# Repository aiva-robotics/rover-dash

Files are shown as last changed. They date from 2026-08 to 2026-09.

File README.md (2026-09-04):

# RC Command Center

Skapa en modern, mobilanpassad webbapplikation för att fjärrstyra en radiostyrd bil med kamera. Designen ska kännas som en professionell kontrollstation för en robot eller FPV-fordon med mörkt tema, glasliknande paneler (glassmorphism), mjuka animationer och responsiv layout.

Layout:

- Överst visas en stor 16:9 livevideoström från Raspberry Pi-kameran med möjlighet till helskärm.

- Ovanpå videon ska en transparent Driving HUD visas med batterinivå, WiFi-signal, hastighet, styrvinkel, gaspådrag, inspelningsindikator och kompass (förberedd för framtida IMU).

- Under videon finns två virtuella joysticks:

  - Vänster joystick styr gas/broms.

  - Höger joystick styr vald RC-utgång på STM32-kortet.

  - Joysticks ska fungera med både touch och mus och automatiskt återgå till mitten när de släpps.

- Nederst finns fyra stora knappar:

  - Strålkastare

  - Tuta

  - Ta bild

  - Stor röd Nödstopp-knapp

Instrumentpanel:

Visa i realtid:

- Batterispänning

- WiFi-signal

- Anslutningsstatus

- Hastighet

- Temperatur (om tillgänglig)

- Ping till bilen

Kommunikation:

- Använd WebSocket.

- Skicka generiska STM32-kommandon kontinuerligt i JSON-format. Appen ansvarar
  för att mappa joystick/reglage till rätt RC-utgångar:

{

  "rc": [0, 0, 0, 0],

  "digital": 0,

  "buzzer": 0

}

- Ta emot status som JSON och uppdatera gränssnittet automatiskt.

Inställningar:

Skapa en inställningssida där användaren kan ändra:

- WebSocket-adress

- Videoadress

- Maxhastighet

- Joystickkänslighet

- Invertera styrning

- Invertera gas

Alla inställningar ska sparas i Local Storage.

Säkerhet:

Om anslutningen bryts ska:

- En stor röd varning visas.

- Alla reglage inaktiveras.

- Gränssnittet tydligt indikera att bilen gått till nödstopp.

Förbered gränssnittet för framtida funktioner:

- GPS-karta

- AI-objektdetektering

- Videoinspelning

- Flera kameror

- Batterihistorik

- Loggpanel

Bygg applikationen i React + TypeScript med en modulär komponentstruktur som är enkel att vidareutveckla.

This project was built with [Lovable](https://lovable.dev).

## Build with Lovable

Continue developing this project in the [Lovable editor](https://lovable.dev/projects/422cf66d-660f-4919-b7d5-5cbf4e8ac53d).

- **Ship faster**: describe what you want to build and Lovable handles the code.
- **Stay in sync**: every change made in Lovable is committed straight to this repository.
- **Full ownership**: this code is yours. Push to `main` on GitHub and your changes sync back into Lovable, ready for your next prompt.

## Development

Prefer working locally? You need Node.js and npm — [install with nvm](https://github.com/nvm-sh/nvm#installing-and-updating).

```sh
git clone <this-repository-url>
cd <repository-name>
npm i
npm run dev
```

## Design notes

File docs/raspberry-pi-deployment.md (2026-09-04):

# Raspberry Pi 3 deployment guide

Run the RC Control Station web app locally on a Raspberry Pi 3 so you can control the car from any device on the same network without relying on the cloud preview.

## What you need

- Raspberry Pi 3 (or newer) with Raspberry Pi OS Lite/Desktop
- SSH access to the Pi (`pi@raspberrypi.local` or its IP address)
- Either a faster dev machine to build the app before copying it, **or** patience to build it directly on the Pi

## How it works

The app is server-rendered, so the Pi runs a small Node server (built with the `node-server` target) behind nginx on port 80. The browser connects directly to the Raspberry Pi camera stream and the car WebSocket server.

You have two deployment options:

1. **Cross-build (recommended)** — Build on your dev machine and copy the server bundle to the Pi. Fast and gentle on the Pi.
2. **Native build** — Download the source to the Pi with `git` and build it there. Useful if you want to edit code directly on the Pi or do not have another computer.

If you already pushed the project to GitHub and want the Pi to fetch and build it automatically, see the **One-command clone + setup** shortcut in Option B.

---

## Option A: Cross-build (recommended)

### One-time Pi setup

SSH into the Pi and run:

```bash
sudo apt update
sudo apt install -y nginx nodejs
sudo systemctl enable nginx
```

### Deploy from your development machine

Set the target host (or edit `scripts/deploy-to-pi.sh`):

```bash
export PI_HOST=pi@raspberrypi.local
export PI_APP_DIR=/home/pi/rc-control-app
```

Use the Pi's IP address if `.local` does not resolve on your network.

Build and deploy:

```bash
NITRO_PRESET=node-server bun run build
bun run deploy:pi
```

This copies the `.output/` server bundle to the Pi, installs the `rc-control` systemd service and the nginx reverse proxy, and starts the app.

Open the app on any device on the same network:

```
http://raspberrypi.local
```

### Updating after code changes

Run the same two commands again:

```bash
NITRO_PRESET=node-server bun run build
bun run deploy:pi
```

---

## Option B: Build natively on the Raspberry Pi

> ⚠️ **Warning:** A Pi 3 only has 1 GB RAM. The Vite/TanStack build is heavy and can take 10–30 minutes, or longer if swap is too small. A Pi 4/5 with more RAM is much more comfortable. The scripts below configure extra swap to make the build possible.

### 1. Download the project from GitHub

SSH into the Pi and clone your repository. Replace the URL below with your own repo URL:

```bash
cd ~
git clone https://github.com/YOUR_USERNAME/YOUR_REPO_NAME.git rc-control-app
cd rc-control-app
```

#### Private repositories

If your GitHub repository is private, use **one** of these methods on the Pi:

**A. SSH key (recommended if you use the Pi often)**

1. Generate or copy an SSH key to the Pi:
   ```bash
   ssh-keygen -t ed25519 -C "pi@raspberrypi"
   cat ~/.ssh/id_ed25519.pub
   ```
2. Add the key in GitHub under **Settings → SSH and GPG keys → New SSH key**.
3. Clone with the SSH URL:
   ```bash
   git clone git@github.com:YOUR_USERNAME/YOUR_REPO_NAME.git rc-control-app
   ```

**B. Personal access token (good for one-command setup)**

1. Create a token in GitHub under **Settings → Developer settings → Personal access tokens → Tokens (classic)**. Give it at least the `repo` scope.
2. On the Pi, export the token and run the helper script:
   ```bash
   export REPO_URL=https://github.com/YOUR_USERNAME/YOUR_REPO_NAME.git
   export GITHUB_TOKEN=ghp_xxxxxxxxxxxxxxxxxxxx
   bash scripts/pi-clone-and-setup.sh
   ```
   The script uses the token only during clone/pull and does **not** save it in `.git/config`.

**C. Manual token clone**

```bash
cd ~
git clone https://ghp_xxxxxxxxxxxxxxxxxxxx@github.com/YOUR_USERNAME/YOUR_REPO_NAME.git rc-control-app
cd rc-control-app
# Remove the token from the stored origin URL so it is not saved on disk
git remote set-url origin https://github.com/YOUR_USERNAME/YOUR_REPO_NAME.git
```

> **Note:** The one-command `curl ... | bash` shortcut below only works for **public** repositories, because `raw.githubusercontent.com` cannot fetch files from a private repo without authentication.

To update the app later after pushing changes from another machine:

```bash
cd ~/rc-control-app
# For a public repo or an SSH-cloned private repo:
git pull
# For a private HTTPS repo with a token:
export GITHUB_TOKEN=ghp_xxxxxxxxxxxxxxxxxxxx
bash scripts/pi-clone-and-setup.sh
bash scripts/pi-build.sh
```

### One-command clone + setup shortcut (public repos only)

If your repo is public and you want the Pi to download, build, and serve the app in one go, SSH in and run:

```bash
export REPO_URL=https://github.com/YOUR_USERNAME/YOUR_REPO_NAME.git
curl -fsSL https://raw.githubusercontent.com/YOUR_USERNAME/YOUR_REPO_NAME/main/scripts/pi-clone-and-setup.sh | bash
```

Or, after cloning once, run the included script directly (this works with `GITHUB_TOKEN` for private repos too):

```bash
export REPO_URL=https://github.com/YOUR_USERNAME/YOUR_REPO_NAME.git
export GITHUB_TOKEN=ghp_xxxxxxxxxxxxxxxxxxxx   # only needed for private repos
bash scripts/pi-clone-and-setup.sh
```

This clones/updates the repo, installs dependencies, builds the app, configures nginx, and enables auto-start on boot.

### 2. Prepare the Pi

Run the setup script inside the project directory:

```bash
cd rc-control-app
bash scripts/pi-build-setup.sh
```

This installs Node.js, bun, nginx, git, and configures a 2 GB swap file.

### 3. Build the app on the Pi

Inside the project directory on the Pi:

```bash
bash scripts/pi-build.sh
```

The script limits Node's memory usage, installs optional dependencies (needed for Rolldown), and builds a self-hosted Node server bundle (`NITRO_PRESET=node-server` → `.output/server/index.mjs`).

When the build finishes it **deploys automatically**:

- installs the `rc-control` systemd service that runs `.output/server/index.mjs` on port 3000 (auto-start on boot)
- installs the nginx reverse proxy config on port 80 and reloads nginx
- starts the service and verifies it is running

Skip the deploy step with:

```bash
DEPLOY=false bash scripts/pi-build.sh
```

Deploy an existing build separately with:

```bash
bash scripts/pi-deploy-local.sh   # or: npm run pi:deploy
```

### 4. Managing the app

```bash
sudo systemctl status rc-control      # is it running?
sudo journalctl -u rc-control -f      # live logs
sudo systemctl restart rc-control     # restart after a rebuild
```

Run the server in the foreground (without systemd) with:

```bash
bash scripts/pi-serve.sh              # PORT=3000 by default
```

---

## No nginx?

The app also works without nginx — it just runs on port 3000 instead of 80:

```
http://raspberrypi.local:3000
```

---

## Troubleshooting

- **`Cannot find module '.../lightningcss.linux-arm64-gnu.node'`**: Tailwind v4 compiles CSS with lightningcss, whose native binary is also an *optional* dependency. `pi-build.sh` now installs `lightningcss-linux-arm64-gnu` automatically; if it still fails, run a clean install as shown below.
- **`Cannot find module './rolldown-binding.linux-arm64-gnu.node'`**: The build tool (Vite 8 / Rolldown) needs a native binary that is installed as an *optional* dependency. Do a clean install with optional deps enabled:
  ```bash
  cd ~/rc-control-app
  rm -rf node_modules package-lock.json
  npm install --include=optional
  bash scripts/pi-build.sh
  ```
  Make sure you are **not** setting `npm_config_optional=false` and that you run the 64-bit Raspberry Pi OS — check with `uname -m` (must print `aarch64`). On a 32-bit OS (`armv7l`) there is no prebuilt binary; either reflash with the 64-bit image or use the cross-build workflow (Option A).
- **`build output not found at dist/client`**: older builds targeted Cloudflare and produced no static site. Pull the latest code and rebuild — `pi-build.sh` now sets `NITRO_PRESET=node-server` and produces `.output/server/index.mjs`.
- **Cannot reach the page**: make sure the Pi firewall allows port 80/3000 and the device is on the same network. Check `sudo systemctl status rc-control`.
- **Page loads but car does not connect**: the browser must be able to reach the WebSocket address configured in Settings. The Pi only serves the web files; it does not proxy the car connection by default.
- **Build fails with OOM / JavaScript heap out of memory**: The Pi 3 needs more swap. Run `scripts/pi-build-setup.sh` again to ensure the 2 GB swap file is active, or increase it further with `sudo dphys-swapfile swapoff && sudo nano /etc/dphys-swapfile`.
- **Build takes forever**: This is expected on a Pi 3. Use the cross-build workflow (Option A) for faster iteration.

## Raspberry Pi-kamera (MJPEG-stream)

Appen visar video via en MJPEG-ström. På Pi:n körs en liten Python-server
(`deployment/pi-camera-server.py`) som använder `picamera2` och levererar
strömmen direkt i ett format webbläsaren förstår.

### Installation

```bash
cd ~/rc-control        # projektmappen på Pi:n
bash scripts/pi-camera-setup.sh
```

Skriptet installerar `python3-picamera2`, lägger till användaren i gruppen
`video`, installerar systemd-tjänsten `pi-camera.service` och startar den.

### Adresser

| Endpoint | Beskrivning |
| --- | --- |
| `http://<pi-ip>:8080/stream` | MJPEG-ström |
| `http://<pi-ip>:8080/snapshot` | Enstaka JPEG-bild |
| `http://<pi-ip>:8080/health` | JSON-status |
| `http://<pi-ip>/camera/stream` | Samma ström via nginx (rekommenderas) |

Sätt **Videoadress** i appens inställningar — det finns två snabbknappar
("Pi-kamera (via nginx)" och "Pi-kamera (port 8080)").

Kör `sudo bash scripts/pi-deploy-local.sh` igen efter uppdateringen så att
nginx får `/camera/`-proxyn.

### Konfiguration

Du kan vända bilden på två ställen:

1. **I appen (rekommenderat)** — gå till **Inställningar** och slå på
   "Vänd bild horisontellt" / "Vänd bild vertikalt". Detta görs med CSS-transform
   i webbläsaren och kostar ingen prestanda.
2. **I kameran (hårdvarunivå)** — sätt `CAM_HFLIP=1` eller `CAM_VFLIP=1` i
   tjänsten. Detta använder libcamera `Transform` och har i princip noll
   prestandapåverkan.

Redigera miljövariablerna i tjänsten:

```bash
sudo systemctl edit --full pi-camera
```

| Variabel | Default | Beskrivning |
| --- | --- | --- |
| `CAM_WIDTH` / `CAM_HEIGHT` | 640 / 480 | Upplösning (Pi 3: håll dig ≤ 1280x720) |
| `CAM_FPS` | 20 | Bildrutor per sekund |
| `CAM_QUALITY` | 75 | JPEG-kvalitet (lägre = mindre bandbredd) |
| `CAM_HFLIP` / `CAM_VFLIP` | 0 | Spegla bilden i kameran (upp och ner / spegelvänd) |

Starta om efter ändring: `sudo systemctl restart pi-camera`

### Felsökning

```bash
sudo systemctl status pi-camera
journalctl -u pi-camera -f
libcamera-hello --list-cameras     # hittas kameran?
curl -I http://localhost:8080/snapshot
```

- **Ingen kamera hittas:** kontrollera flatkabeln (blå sida mot Ethernet-porten)
  och att `camera_auto_detect=1` finns i `/boot/firmware/config.txt` (Bookworm).
- **"Device or resource busy":** något annat använder kameran — stoppa
  `libcamera-vid`/`motion` eller kör `sudo systemctl restart pi-camera`.
- **Hackig bild på Pi 3:** sänk `CAM_FPS` till 15 och `CAM_QUALITY` till 60.

---

## Styrserver: WebSocket till STM32 UART (rc-car-server)

Pi:n tar emot WebSocket-kommandon från appen och skickar dem vidare till
STM32-kortet över `/dev/serial0`. STM32-kortet hanterar RC-utgångar,
digitala utgångar, buzzer, status och OLED.

### Koppling

| Signal | Raspberry Pi 3 | STM32 |
| --- | --- | --- |
| UART TX | GPIO14 / pin 8 | STM32 UART RX |
| UART RX | GPIO15 / pin 10 | STM32 UART TX |
| GND | pin 6 / 9 / 14 / 20 / 25 / 30 / 34 / 39 | GND |
| Power-off ready | GPIO26 / pin 37 | RPI_POWER_OFF_OK |

RC-servon och digitala utgångar kopplas till STM32-kortets utgångar, inte
direkt till Raspberry Pi GPIO.

### Installation

```bash
bash scripts/pi-car-server-setup.sh
```

Skriptet installerar Python/WebSocket/serial-beroenden och tjänsten
`rc-car-server` (startar automatiskt vid boot, port 81).

Sätt **WebSocket-adress** i inställningarna till `ws://<pi-ip>:81` (eller tryck
på snabbknappen "Pi WebSocket (samma värd)").

### Beteende

- Tar emot generiska STM32-kommandon:
  `{"rc": [0, 0, 0, 0], "digital": 0, "buzzer": 0}`.
- Mappning av joystick, servo, motor, lampor och buzzer görs i webbappen.
- Svarar `{"pong": ...}` på ping så appen kan mäta latens.
- Skickar telemetri 5 ggr/s (hastighet, CPU-temp, WiFi-RSSI, status).
- **Watchdog:** inga kommandon på 0,5 s → generiska RC-kommandon till neutral.
- **En förare i taget** — en ny klient tar över och den gamla får ett tydligt
  felmeddelande i appen.
- STM32-bron armeras med 2 s neutrala kommandon vid start.

Justera UART-port, heartbeat, auth-token och timeouts med
`sudo systemctl edit --full rc-car-server`.

### Felsökning

```bash
sudo systemctl status rc-car-server
journalctl -u rc-car-server -f
```

---

## Statusskärm

Statusskärmen (IP-adress m.m.) hanteras numera av STM32-kortet på Raspberry
Pi-hatten, inte av någon tjänst på Pi:n.

---

## Uppdatera allt med ett kommando

```bash
bash scripts/pi-deploy-all.sh
```

Skriptet:

1. hämtar senaste koden från GitHub (`GITHUB_TOKEN=xxx` för privata repon),
2. bygger webbappen,
3. installerar/uppdaterar alla systemd-tjänster (webb, kamera, styrserver),
4. aktiverar dem så de startar vid boot och skriver ut en hälsokontroll.

Användbara flaggor: `SKIP_BUILD=1`, `WITH_CAMERA=0`,
`WITH_CAR_SERVER=0`, `BRANCH=main`.

## Åtkomsttoken (autentisering)

Utan token kan vem som helst på nätverket styra bilen. Sätt en delad hemlighet:

```bash
sudo systemctl edit --full rc-car-server   # ändra Environment=RC_TOKEN=minhemlighet
sudo systemctl restart rc-car-server
```

Ange samma värde i appen under **Inställningar → Åtkomsttoken**. Appen lägger på
det som `?token=...` på WebSocket-adressen; fel token ger felmeddelandet
"Fel åtkomsttoken" i gränssnittet.

## Tillbehör och säkerhet (uppdaterat)

Nya miljövariabler för `rc-car-server.service`:

| Variabel | Standard | Beskrivning |
| --- | --- | --- |
| `RC_SNAPSHOT_URL` | `http://127.0.0.1:8080/snapshot` | Källa för "Ta bild" |
| `RC_PHOTO_DIR` | `/var/lib/rc-car/photos` | Där bilder sparas |

Åtkomsttoken skickas numera i WebSocket-handskakningen (`Sec-WebSocket-Protocol`)
istället för i URL:en, så den hamnar inte i nginx- eller proxyloggar. Servern
accepterar fortfarande `?token=` från äldre klienter men loggar en varning.

Appen upptäcker även "halvöppna" anslutningar: om bilen slutar svara på ping
inom 3,5 sekunder kopplas socketen ner, varningen visas och reglagen låses.

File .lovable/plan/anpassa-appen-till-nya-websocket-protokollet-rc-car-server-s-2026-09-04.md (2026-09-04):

# Anpassa appen till nya WebSocket-protokollet (rc-car-server.service)

Servern (STM32-bryggan) accepterar inte längre `{throttle, steering}`. Den förväntar sig
`{"rc": [c1, c2, c3, c4], "digital": 0..15, "buzzer": 0..65535}` med värden -1000..1000,
plus `{"estop": bool}` och `{"action": ...}`. Appen skickar fortfarande det gamla formatet,
så styrningen når aldrig hårdvaran.

## Vad som ändras

1. **Kommandoformat**
   - Skala appens -100..100 till -1000..1000.
   - Kanal 1 (index 0) = styrning, kanal 3 (index 2) = gas. Kanal 2 och 4 skickas som 0.
   - `estop` skickas som idag i samma paket.
   - Kommandot skickas fortfarande med 20 Hz (serverns watchdog kräver det).

2. **Tillbehör mot rätt fält**
   - Ljus: digital utgång bit 0 (`digital: 1`), skickas som del av det löpande kommandot
     så att STM32:ans failsafe inte släcker det.
   - Tuta: `buzzer` sätts till 2000 Hz medan knappen hålls/aktiveras, annars 0.
   - `sendAction("headlights"/"horn")` tas bort — servern känner inte igen dem.

3. **Telemetri och status**
   - Ljusstatus läses från serverns eko (`stm32.digitalMask`) istället för `status.headlights`.
   - `failsafe` från STM32 visas som varningsläge i gränssnittet (finns redan i typen).
   - Batteri kommer nu från INA226 (`battery` i volt) — befintlig visning fungerar,
     men procentskalan justeras inte i denna ändring.

4. **Typer**
   - `DriveCommand` utökas med `digital` och `buzzer` (valfria) i `src/lib/car-protocol.ts`.
   - `CarStatus` får `stm32?`-fältet typat så att digitalMask/failsafe kan läsas säkert.

## Berörda filer

- `src/lib/car-protocol.ts` – typer + skalningshjälpare (`toRcValue`).
- `src/hooks/useCarSocket.ts` – bygger `{rc, digital, buzzer, estop}`-paketet i sändloopen.
- `src/routes/index.tsx` – ljus/tuta styr nu kommandots `digital`/`buzzer`; läser ljusstatus
  från `stm32.digitalMask`.
- `src/components/car/ControlButtons.tsx` – oförändrat API, endast anropen kopplas om.

Inga ändringar i serverkoden eller deployment-skripten behövs.

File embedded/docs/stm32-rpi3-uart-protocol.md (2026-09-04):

# Rover Dash STM32 to Raspberry Pi 3 UART Protocol

This document describes the UART protocol used between the Rover Dash STM32 controller and a Raspberry Pi 3. It is intended as an architectural reference for reimplementing the Raspberry Pi side in another language, runtime, or application.

## Purpose

The Raspberry Pi is the high-level controller. The STM32 is the real-time I/O controller.

The Raspberry Pi sends control commands to the STM32 for:

- 4 generic RC PWM outputs
- 4 digital outputs
- Buzzer frequency
- Optional OLED framebuffer content

The STM32 sends status and telemetry back to the Raspberry Pi containing:

- Command echo
- Failsafe state
- Raspberry Pi power-management state
- ADC values
- NTC raw value
- TMP75 temperature
- Speed sensor value
- INA226 voltage and current

The STM32 can also send a shutdown request to the Raspberry Pi.

## Physical Link

```text
UART:        115200 baud
Data bits:   8
Parity:      none
Stop bits:   1
Flow control: none
Framing:     COBS + 0x00 delimiter
```

Each UART frame is COBS encoded and terminated with byte `0x00`.

## Packet Format Before COBS

Before COBS encoding, every packet has this format:

```text
byte 0:       message type
byte 1:       payload length
bytes 2..N:   payload
last 2 bytes: CRC16-CCITT, little-endian
```

The CRC is calculated over:

```text
message type + payload length + payload
```

CRC settings:

```text
CRC16-CCITT
Polynomial: 0x1021
Initial value: 0xFFFF
Output byte order: little-endian
```

## Message Types

```text
0x01 CONTROL       Raspberry Pi -> STM32
0x02 RPI_SHUTDOWN  STM32 -> Raspberry Pi
0x03 DISPLAY_DATA  Raspberry Pi -> STM32
0x04 DISPLAY_UPDATE Raspberry Pi -> STM32
0x05 RPI_INFO      Raspberry Pi -> STM32
0x80 STATUS        STM32 -> Raspberry Pi
0x81 DIAGNOSTICS   Reserved/optional
```

## CONTROL Packet

Direction:

```text
Raspberry Pi -> STM32
```

Message type:

```text
0x01
```

Payload length:

```text
11 bytes
```

Payload layout:

```text
0-1:  RC Output 0, int16 little-endian, range -1000..1000, maps to PA11
2-3:  RC Output 1, int16 little-endian, range -1000..1000, maps to PA10
4-5:  RC Output 2, int16 little-endian, range -1000..1000, maps to PA9
6-7:  RC Output 3, int16 little-endian, range -1000..1000, maps to PA8
8:    digital output bitmask, uint8
9-10: buzzer frequency Hz, uint16 little-endian
```

Digital output bitmask:

```text
bit 0: Digital Output 0, PA6
bit 1: Digital Output 1, PA7
bit 2: Digital Output 2, PB0
bit 3: Digital Output 3, PB1
```

Buzzer behavior:

```text
0 Hz:  buzzer off
>0 Hz: buzzer on at requested frequency
```

RC output scaling on STM32:

```text
-1000 -> 1000 us pulse
0     -> 1500 us pulse
+1000 -> 2000 us pulse
```

The Raspberry Pi should send `CONTROL` periodically while active. A good default rate is `20 Hz`. The STM32 output failsafe timeout is currently `1000 ms`; if no valid `CONTROL` packet is received within that time, RC outputs return to neutral, digital outputs turn off, and the buzzer turns off.

## RPI_SHUTDOWN Packet

Direction:

```text
STM32 -> Raspberry Pi
```

Message type:

```text
0x02
```

Payload length:

```text
0 bytes
```

Meaning:

The STM32 requests that the Raspberry Pi shut down cleanly.

The Raspberry Pi should respond by starting its OS shutdown sequence. Before final poweroff, the Raspberry Pi should assert its shutdown-ready signal connected to:

```text
STM32 input:       RPI_POWER_OFF_OK
Raspberry Pi GPIO: GPIO26
```

The STM32 then disables `REG_5V_EN` and removes Raspberry Pi power.

## OLED Ownership And Framebuffer Display

The STM32 owns the physical OLED display at all times. The Raspberry Pi must not access the OLED I2C bus directly. If the Raspberry Pi wants to draw on the OLED, it sends a complete 128x32 monochrome framebuffer over UART and the STM32 decides whether to show it.

The STM32 keeps two independent 512-byte framebuffers:

```text
local_framebuffer: STM32-generated status and warning display
rpi_framebuffer:   latest complete framebuffer received from Raspberry Pi
```

The OLED framebuffer is arranged as 4 pages of 128 bytes. Each byte represents one vertical column of 8 pixels, matching the SSD1306 page format.

At startup the active display source is always STM32/local. This lets the STM32 show local startup and power-management messages before the Raspberry Pi has booted.

Typical local STM32 messages include:

```text
ROVERCORE
STARTING...

RASPBERRY PI
BOOTING...

RASPBERRY PI
CONNECTED

RASPBERRY PI
SHUTDOWN

RASPBERRY PI
POWER OFF

POWER FAULT
PI DISABLED
```

### DISPLAY_DATA Packet

Direction:

```text
Raspberry Pi -> STM32
```

Message type:

```text
0x03
```

Payload layout:

```text
byte 0:     chunk number, 0..8
bytes 1..N: framebuffer data bytes
```

Chunk sizes:

```text
chunks 0..7: payload length 64 bytes, containing 63 framebuffer bytes
chunk 8:     payload length 9 bytes, containing 8 framebuffer bytes
```

For compatibility, the STM32 also accepts chunk `8` with payload length `64` and ignores padding beyond the final 8 framebuffer bytes.

The framebuffer byte offset for each chunk is:

```text
offset = chunk_number * 63
```

Receiving `DISPLAY_DATA` does not immediately change what is shown on the OLED. The STM32 only stores the data in `rpi_framebuffer`.

### DISPLAY_UPDATE Packet

Direction:

```text
Raspberry Pi -> STM32
```

Message type:

```text
0x04
```

Payload length:

```text
0 bytes
```

When `DISPLAY_UPDATE` is received, the STM32 shows `rpi_framebuffer` only if all 9 chunks have been received. Incomplete framebuffer transfers are ignored and the currently displayed source remains unchanged.

The Raspberry Pi does not need to retransmit the framebuffer after a temporary STM32 local display override. The STM32 keeps the latest valid Raspberry Pi framebuffer stored separately.

The Raspberry Pi should keep the periodic `CONTROL` stream running while sending display chunks. Display packets count as Raspberry Pi communication, but they do not refresh the output-control failsafe timer.

At `115200 baud`, one full-size encoded display chunk takes roughly `6 ms` on the UART line. The STM32 UART receive path is sized to accept a complete 9-chunk display burst, but the Raspberry Pi should still serialize writes in order and avoid overlapping writes from multiple async producers.

## RPI_INFO Packet

Direction:

```text
Raspberry Pi -> STM32
```

Message type:

```text
0x05
```

Payload length:

```text
1..15 bytes
```

Payload layout:

```text
0..N: Raspberry Pi IPv4 address as ASCII text, without NUL terminator
```

Example payload:

```text
31 39 32 2E 31 36 38 2E 31 2E 34 32
```

This represents:

```text
192.168.1.42
```

The Raspberry Pi should send this packet after opening the UART and whenever the active IP address changes. The STM32 stores the address and displays it on the connected Raspberry Pi status screen.

## STATUS Packet

Direction:

```text
STM32 -> Raspberry Pi
```

Message type:

```text
0x80
```

Payload length:

```text
56 bytes
```

Payload layout:

```text
0-3:   uptime_ms, uint32 little-endian

4-5:   RC Output 0 echo, int16 little-endian
6-7:   RC Output 1 echo, int16 little-endian
8-9:   RC Output 2 echo, int16 little-endian
10-11: RC Output 3 echo, int16 little-endian

12:    digital_output_mask, uint8
13:    failsafe_active, uint8 boolean
14-15: buzzer_frequency_hz, uint16 little-endian

16-19: uart_rx_frames, uint32 little-endian
20-23: uart_crc_errors, uint32 little-endian
24-27: failsafe_count, uint32 little-endian

28-29: rpi_connected, uint16 boolean little-endian
30:    rpi_power_enabled, uint8 boolean
31:    rpi_poweroff_ok, uint8 boolean
32:    rpi_shutdown_requested, uint8 boolean
33:    rpi_status, uint8

34-35: ADC PA0 raw, uint16 little-endian
36-37: ADC PA1 raw, uint16 little-endian
38-39: ADC PA2 raw, uint16 little-endian
40-41: ADC PA3 raw, uint16 little-endian

42-43: NTC PA4 raw, uint16 little-endian

44-45: TMP75 temperature, int16 little-endian, centi-Celsius
46:    TMP75 valid flag, uint8 boolean

47-50: speed_hz_x100, uint32 little-endian

51-52: INA226 bus voltage, uint16 little-endian, millivolts
53-54: INA226 current, int16 little-endian, milliamps
55:    INA226 valid flag, uint8 boolean
```

Display conversions:

```text
uptime_s = uptime_ms / 1000
tmp75_c = tmp75_centi_c / 100
speed_hz = speed_hz_x100 / 100
ina226_voltage_v = ina226_bus_voltage_mv / 1000
ina226_current_a = ina226_current_ma / 1000
```

`rpi_status` values:

```text
0: Boot delay
1: Waiting for ready
2: Running
3: Shutdown requested
4: Powered off
5: Forced off
```

## Startup And Power Behavior

On STM32 startup:

1. `REG_5V_EN` is held low.
2. STM32 waits approximately `100 ms`.
3. STM32 enables `REG_5V_EN`.
4. STM32 enters forced failsafe while waiting for the Raspberry Pi.
5. When the Raspberry Pi starts sending valid `CONTROL` packets, STM32 marks `rpi_connected` true.
6. Forced failsafe is released.

While in failsafe:

```text
RC outputs     -> neutral
digital outputs -> off
buzzer         -> off
```

## Shutdown Behavior

If the user presses the power button on STM32:

1. STM32 enters failsafe.
2. STM32 sends an `RPI_SHUTDOWN` packet.
3. STM32 repeats the shutdown packet until `RPI_POWER_OFF_OK` is detected.
4. Raspberry Pi should assert GPIO26 when it is safe to remove power.
5. STM32 disables `REG_5V_EN`.

If the user holds the power button for a long press, currently around `3000 ms`, the STM32 forces Raspberry Pi power off by disabling `REG_5V_EN`.

## Raspberry Pi Implementation Requirements

A Raspberry Pi implementation should:

1. Open UART at `115200 8N1`.
2. Read bytes continuously.
3. Split frames on `0x00`.
4. Ignore empty frames.
5. COBS-decode each frame.
6. Validate packet length.
7. Validate CRC.
8. Dispatch by message type.
9. Send `CONTROL` packets periodically while running.
10. Listen for `RPI_SHUTDOWN`.
11. On shutdown request, safely stop application logic and initiate OS shutdown.
12. Assert GPIO26 / `RPI_POWER_OFF_OK` before final poweroff if hardware and software allow it.

The Pi should treat invalid CRC, invalid COBS, or wrong payload length as protocol errors and ignore that frame.

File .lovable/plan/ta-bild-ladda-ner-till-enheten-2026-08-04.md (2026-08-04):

# Ta bild – ladda ner till enheten

Fotoknappen finns redan men sparar bilden på bilens SD-kort. Nu ska ett tryck även ge dig bilden direkt i telefonen/datorn.

## Så fungerar det

- Tryck på **Bild** (samma knapp som idag, även i helskärm) → aktuell bildruta från videoströmmen fångas och laddas ner som JPEG.
- Filnamn: `rc-bild-ÅÅÅÅMMDD-HHMMSS.jpg`.
- Kort visuell bekräftelse: en snabb "blixt" över videon plus en rad i loggen ("Bild sparad: …").
- Bilden speglas/vänds precis som videon visas, så nedladdningen matchar det du ser.
- Fungerar även i demoläge? Nej – utan videoström visas ett tydligt meddelande "Ingen videoström att fånga".
- Bilden sparas fortfarande på bilen som tidigare (oförändrat beteende).

## Teknisk lösning

**`src/components/car/VideoFeed.tsx`**
- Exponera en `captureFrame()`-funktion via `useImperativeHandle` (forwardRef) som ritar `imgRef.current` till en offscreen `<canvas>` i naturlig upplösning, applicerar `videoFlipH`/`videoFlipV` som canvas-transform, och returnerar en `Blob` via `canvas.toBlob(..., "image/jpeg", 0.92)`.
- Sätt `crossOrigin="anonymous"` på `<img>` så att canvasen inte blir "tainted" när kameraservern ligger på en annan port/origin (den skickar redan `Access-Control-Allow-Origin: *`).
- Fallback när canvas ändå är tainted eller bilden inte laddat: hämta `/<samma bas>/snapshot` med `fetch` och använd den blobben.
- Lägg till en kort blixt-overlay (150 ms, CSS-opacity) vid lyckad fångst.

**`src/routes/index.tsx`**
- Ny `videoRef` till `VideoFeed`.
- `onPhoto` blir en `handlePhoto()`-callback: skickar `sendAction("photo")` som idag, anropar `videoRef.current?.captureFrame()`, skapar en objekt-URL och triggar nedladdning via ett temporärt `<a download>`-element (URL:en revokeas direkt efter).
- Fel loggas som `log("error", …)` i den befintliga loggpanelen.

Inga ändringar behövs på Raspberry Pi-sidan.

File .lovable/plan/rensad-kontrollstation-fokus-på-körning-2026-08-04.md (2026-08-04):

# Rensad kontrollstation — fokus på körning

Idag visas allt samtidigt på startsidan: video + HUD, förarpanel, telemetri (6 rutor), joysticks, knappar, anslutningshälsa (12 mätvärden), framtidspaneler och logg. Det blir en lång, rörig sida där det viktiga (video, styrning, nödstopp) drunknar.

## Nytt upplägg

**Alltid synligt (ovanför "vecket"):**
- Videoströmmen med HUD (batteri, wifi, hastighet, gas/ratt, läge)
- Joysticks
- Kontrollknappar (ljus, tuta, foto, nödstopp)
- En smal statusrad högst upp: AIVA Robotics-logga till vänster, anslutningsprick + ping + batteri + "Du styr"/"Annan styr" i komprimerad form till höger

**Dolt bakom en "Detaljer"-panel (utfällbar längst ner, stängd som standard):**
- Full telemetri (spänning, dBm, temperatur, hastighet, ping)
- Anslutningshälsa (jitter, min/medel/max, paketförlust, försök, meddelanden)
- Förarpanel med sessions-ID och övertagningshistorik
- Logg

**Fortsatt påträngande när det behövs:**
- Nödstopp och anslutningsbortfall visas som idag med tydligt överlägg — ingenting av säkerhetsvärde göms.
- Om anslutningen tappas eller pingen blir dålig lyfts ett kort felmeddelande upp i statusraden även om detaljpanelen är stängd.

## Teknisk avgränsning

- Endast presentation ändras. `useCarSocket`, protokoll, inställningar och serverkod rörs inte.
- Ny komponent `src/components/car/StatusBar.tsx` (kompakt topprad) som innehåller AIVA Robotics-loggan.
- Loggan renderas som text/SVG ("AIVA Robotics") i subtil stil — ingen bildresurs krävs, men om användaren har en logotypfil kan den ersätta texten senare.
- Ny komponent `src/components/car/DetailsDrawer.tsx` som samlar befintliga `TelemetryPanel`, `ConnectionHealthPanel`, `DriverPanel` och `LogPanel` i en shadcn `Accordion`/`Collapsible`, öppet läge sparas i localStorage via befintlig settings-hook-stil (eller lokal state om vi vill hålla settings orörd).
- `FuturePanels` (GPS/AI-platshållare) tas bort helt från sidan och komponentfilen raderas.
- `src/routes/index.tsx` byggs om till: header/statusrad → video+HUD → joysticks → knappar → detaljlåda.
- Befintliga paneler behålls oförändrade internt, bara flyttade.

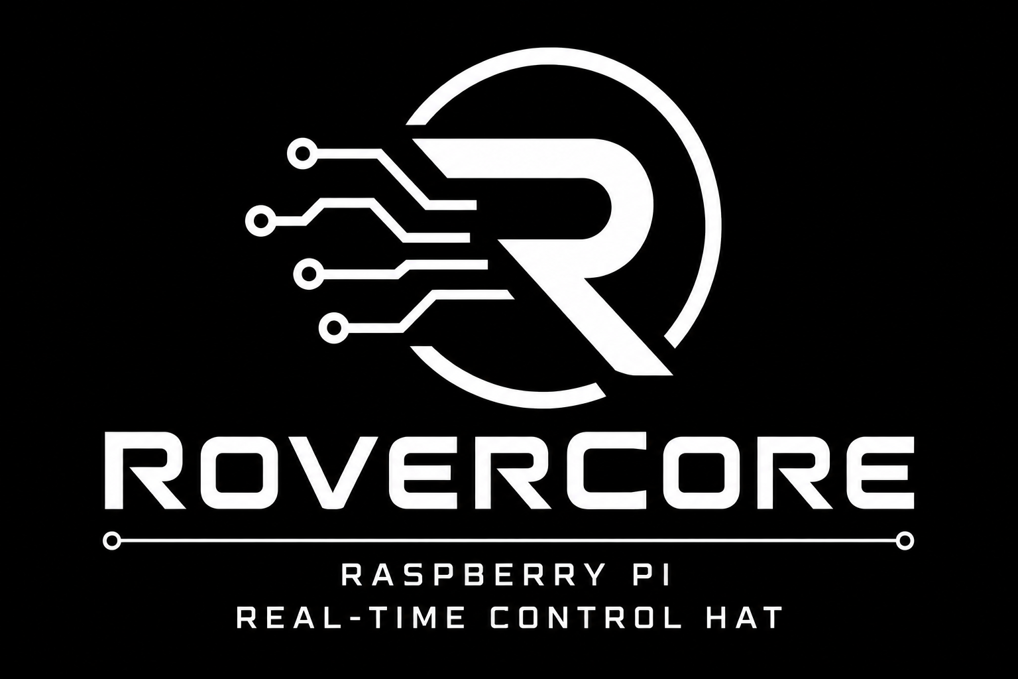
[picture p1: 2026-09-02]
rovercore.png

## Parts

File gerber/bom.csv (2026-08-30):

RefDes | Value | Name | Part | Pattern
C1 | 1uF | CAP_0805 | Part 1 | CAP_0603_N
C2 | 1uF | CAP_0805 | Part 1 | CAP_0603_N
C3 | 100nF | CAP_0805 | Part 1 | CAP_0603_N
C4 | 100nF | CAP_0805 | Part 1 | CAP_0603_N
C5 | 100nF | CAP_0805 | Part 1 | CAP_0603_N
C6 | 100nF | CAP_0805 | Part 1 | CAP_0603_N
C7 | 100nF | CAP_0805 | Part 1 | CAP_0603_N
C8 | 100nF | CAP_0805 | Part 1 | CAP_0603_N
C9 | 100nF | CAP_0805 | Part 1 | CAP_0603_N
C10 | 100nF | CAP_0805 | Part 1 | CAP_0603_N
C11 | 100nF | CAP_0805 | Part 1 | CAP_0603_N
C12 | 1uF | CAP_0805 | Part 1 | CAP_0603_N
C13 | 100nF | CAP_0805 | Part 1 | CAP_0603_N
C15 | 100nF | CAP_0805 | Part 1 | CAP_0603_N
D6 |  | LED_0805(2012 Metric)_N_Blue | Part 1 | LED_0805(2012 Metric)_N_Blue
J1 |  | RaspberryPi IO | Part 1 | HDR-2x20
JP1 |  | IDC_2pins | Part 1 | IDC_1x2
JP6 |  | IDC_2pins | Part 1 | IDC_1x2
JP7 |  | IDC_4pins | Part 1 | HDR-2x2
JP8 |  | IDC_4pins | Part 1 | IDC_1x4
JP15 |  | IDC_3pins | Part 1 | IDC_1x3
JP16 |  | IDC_2pins | Part 1 | IDC_1x2
L1 |  | IND_FERRITE_BEAD | Part 1 | RES_0603_N
LS1 |  | BUZZER | Part 1 | Buzzer
MD1 |  | S13V30F5 | Part 1 | D:\OneDrive\Documents\DipTrace\My Libraries
Q2 |  | AO3400A | Part 1 | SOT23-3P95_280X125L45X40N_AD1
Q3 |  | AO3400A | Part 1 | SOT23-3P95_280X125L45X40N_AD1
Q4 |  | AO3400A | Part 1 | SOT23-3P95_280X125L45X40N_AD1
Q5 |  | AO3400A | Part 1 | SOT23-3P95_280X125L45X40N_AD1
R1 | 220 | RES_0805 | Part 1 | RES_0603_N
R2 | 220 | RES_0805 | Part 1 | RES_0603_N
R3 | 4k7 | RES_0805 | Part 1 | RES_0603_N
R4 | 4k7 | RES_0805 | Part 1 | RES_0603_N
R5 |  | RES_0805 | Part 1 | RES_0603_N
R6 | 220 | RES_0805 | Part 1 | RES_0603_N
R7 | 220 | RES_0805 | Part 1 | RES_0603_N
R8 | 100k | RES_0805 | Part 1 | RES_0603_N
R9 | 100k | RES_0805 | Part 1 | RES_0603_N
R10 | 100k | RES_0805 | Part 1 | RES_0603_N
R11 | 10k | RES_0805 | Part 1 | RES_0603_N
R12 | 100k | RES_0805 | Part 1 | RES_0603_N
R13 | 100 | RES_0805 | Part 1 | RES_0603_N
R14 | 100 | RES_0805 | Part 1 | RES_0603_N
R15 | 100 | RES_0805 | Part 1 | RES_0603_N
R16 | 100 | RES_0805 | Part 1 | RES_0603_N
R17 | 100 | RES_0805 | Part 1 | RES_0603_N
R19 | 12k | RES_0805 | Part 1 | RES_0603_N
R20 | 20k | RES_0805 | Part 1 | RES_0603_N
R21 | 1k | RES_0805 | Part 1 | RES_0603_N
R22 | 12k | RES_0805 | Part 1 | RES_0603_N
R23 | 20k | RES_0805 | Part 1 | RES_0603_N
R24 | 1k | RES_0805 | Part 1 | RES_0603_N
R25 | 12k | RES_0805 | Part 1 | RES_0603_N
R26 | 20k | RES_0805 | Part 1 | RES_0603_N
R27 | 1k | RES_0805 | Part 1 | RES_0603_N
R28 | 12k | RES_0805 | Part 1 | RES_0603_N
R29 | 20k | RES_0805 | Part 1 | RES_0603_N
R30 | 1k | RES_0805 | Part 1 | RES_0603_N
R31 | 1k | RES_0805 | Part 1 | RES_0603_N
R32 | 10k | RES_0805 | Part 1 | RES_0603_N
R33 | 10k | RES_0805 | Part 1 | RES_0603_N
R34 | 1k | RES_0805 | Part 1 | RES_0603_N
R35 | 10k | RES_0805 | Part 1 | RES_0603_N
R36 | 10k | RES_0805 | Part 1 | RES_0603_N
R37 | 1k | RES_0805 | Part 1 | RES_0603_N
S1 |  | Switch_4x3mm_SMD | Part 1 | Switch_4x3mm_SMD
U1 |  | STM32G4A1CET | Part 1 | QFP48P50_900X900X120L50X22N
U2 |  | TagConnect | Part 1 | TagConnector
U3 |  | TPS7A24 | Part 1 | SOT23-5P95_280X145L45X40
U4 |  | TMP1075 | Part 1 | SOIC8P127_493X599X173L64X41L_AD4
U5 |  | IDC_2.54mm_3x4_straight | Part 1 | 2.54mm 3x4 straight
U6 |  | IDC_2.54mm_3x4_straight | Part 1 | 2.54mm 3x4 straight
U7 |  | IDC_2.54mm_3x4_straight | Part 1 | 2.54mm 3x4 straight
 |  | NTC
 |  | IN226
 |  | HALL Sensor DRV5033

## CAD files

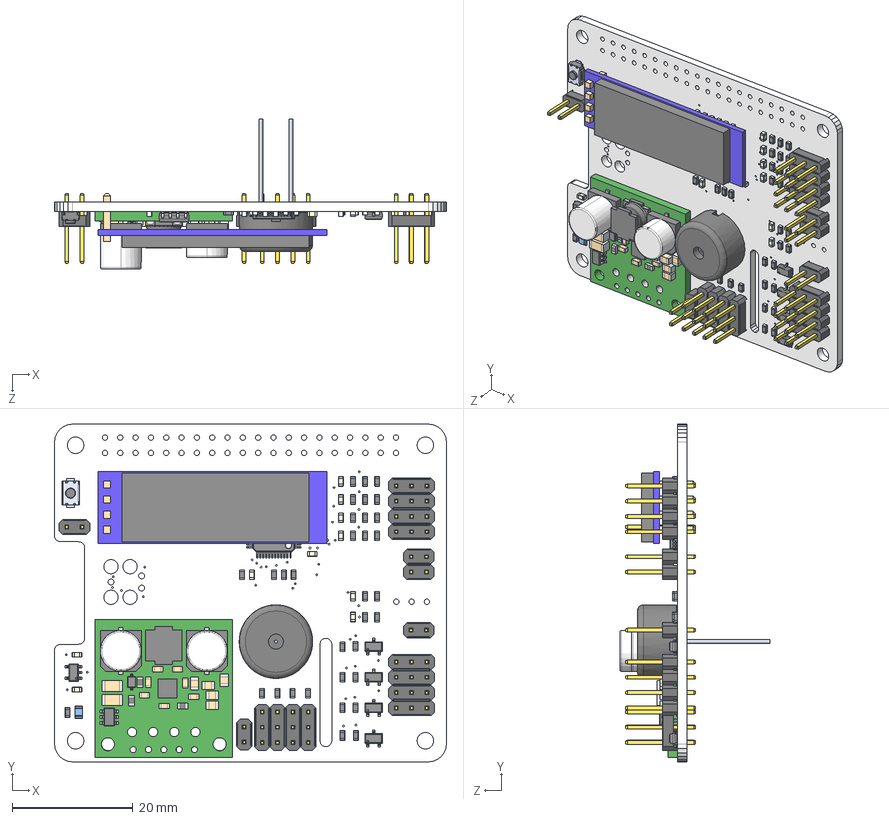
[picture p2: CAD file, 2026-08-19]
3d/mainboard.step
65.0 x 56.0 x 24.9 mm
Board_mainboard
CAP_0805 x 14
led_0805(2012_metric)_blue
PLD-2 x 3
PLD-4
UGV_OLED_Display_32x128
IND_FERRITE_BEAD x 37
PS1240P02BT
5v-step-up-step-down-voltage-regulator-s13v30f5
AO3400A x 4
TS-1088-AR02016--3DModel-STEP-269445
STM32G4A1KE
TPS7A24
TMP1075
PLT-12 x 3

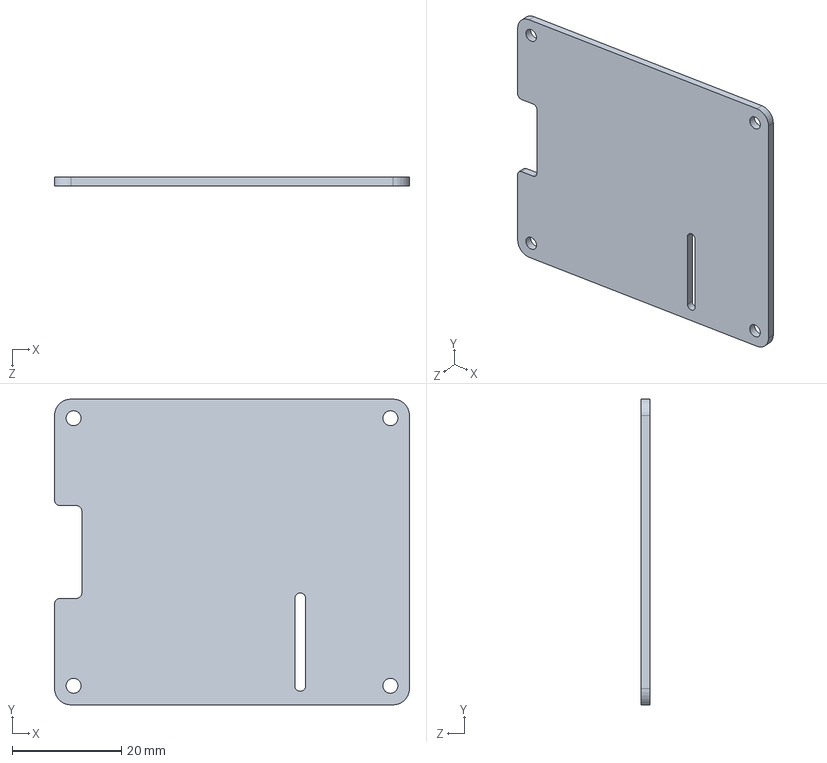
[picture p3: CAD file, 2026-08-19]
3d/raspberry_pi_hat.SLDPRT
65.0 x 56.0 x 1.60 mm

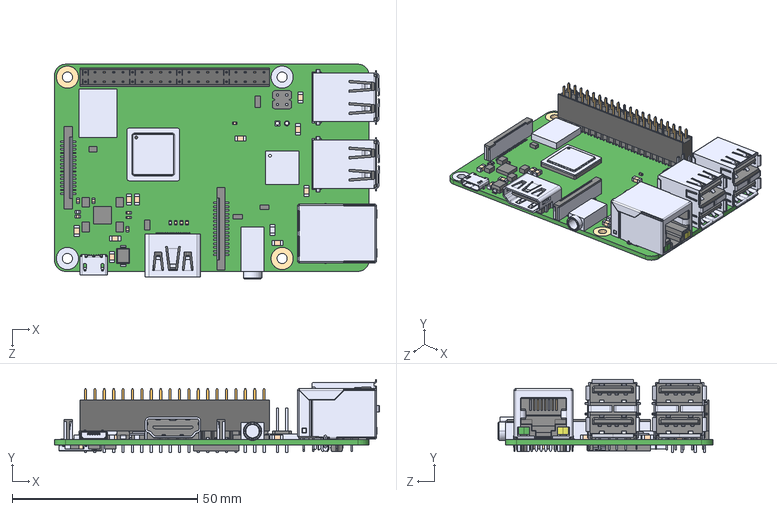
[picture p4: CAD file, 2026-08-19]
3d/RASPBERRY PI 3 + Female Header.STEP
87.8 x 19.8 x 58.0 mm
RASPBERRY PI 3 MODEL B---3DModel-STEP-56544
40-Pin Header - Female - Double - 2.54mm

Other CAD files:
3d/RASPBERRY PI 3 + Female Header.SLDASM
3d/mainboard.SLDASM
3d/raspberry_pi_hat.DXF

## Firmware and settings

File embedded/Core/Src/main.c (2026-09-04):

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
/* Includes ------------------------------------------------------------------*/
#include "main.h"

/* USER CODE BEGIN Includes */
#include "app.h"
#include "adc_task.h"
#include "speed_task.h"
#include "uart_task.h"

/* USER CODE END Includes */

ADC_HandleTypeDef hadc1;
ADC_HandleTypeDef hadc2;
DMA_HandleTypeDef hdma_adc1;

I2C_HandleTypeDef hi2c1;

TIM_HandleTypeDef htim1;
TIM_HandleTypeDef htim2;
TIM_HandleTypeDef htim4;
TIM_HandleTypeDef htim6;

UART_HandleTypeDef huart2;
DMA_HandleTypeDef hdma_usart2_tx;

void SystemClock_Config(void);
static void MX_GPIO_Init(void);
static void MX_DMA_Init(void);
static void MX_ADC1_Init(void);
static void MX_ADC2_Init(void);
static void MX_TIM1_Init(void);
static void MX_TIM2_Init(void);
static void MX_TIM4_Init(void);
static void MX_I2C1_Init(void);
static void MX_USART2_UART_Init(void);
static void MX_TIM6_Init(void);
/**
  * @brief  The application entry point.
  * @retval int
  */
int main(void)
{

  /* MCU Configuration--------------------------------------------------------*/

  /* Reset of all peripherals, Initializes the Flash interface and the Systick. */
  HAL_Init();

  /* Configure the system clock */
  SystemClock_Config();

  /* Initialize all configured peripherals */
  MX_GPIO_Init();
  MX_DMA_Init();
  MX_ADC1_Init();
  MX_ADC2_Init();
  MX_TIM1_Init();
  MX_TIM2_Init();
  MX_TIM4_Init();
  MX_I2C1_Init();
  MX_USART2_UART_Init();
  MX_TIM6_Init();
  /* USER CODE BEGIN 2 */
  app_init();

  /* USER CODE END 2 */

  /* Infinite loop */
  /* USER CODE BEGIN WHILE */
  while (1)
  {
    /* USER CODE END WHILE */

    /* USER CODE BEGIN 3 */
    app_run();
  }
  /* USER CODE END 3 */
}

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
/* USER CODE BEGIN 4 */
void HAL_ADC_ConvCpltCallback(ADC_HandleTypeDef *hadc)
{
  adc_task_dma_full_callback(hadc);
}

void HAL_UART_RxCpltCallback(UART_HandleTypeDef *huart)
{
  uart_task_rx_complete_callback(huart);
}

void HAL_UART_ErrorCallback(UART_HandleTypeDef *huart)
{
  uart_task_error_callback(huart);
}

void HAL_TIM_IC_CaptureCallback(TIM_HandleTypeDef *htim)
{
  speed_task_capture_callback(htim);
}

/* USER CODE END 4 */
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


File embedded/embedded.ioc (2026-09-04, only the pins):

Mcu.UserName=STM32G491CETx
PA0.GPIO_Label=ADC_0
PA0.Signal=ADC1_IN1
PA1.GPIO_Label=ADC_1
PA1.Signal=ADC1_IN2
PA10.GPIO_Label=RC_OUTPUT_1
PA10.Signal=S_TIM1_CH3
PA11.GPIO_Label=RC_OUTPUT_0
PA11.Signal=S_TIM1_CH4
PA12.GPIO_Label=BUZZER
PA12.Signal=S_TIM4_CH2
PA2.GPIO_Label=ADC_2
PA2.Signal=ADC1_IN3
PA3.GPIO_Label=ADC_3
PA3.Signal=ADC1_IN4
PA4.GPIO_Label=MOTOR_TEMP
PA4.Signal=ADC2_IN17
PA6.GPIO_Label=OUTPUT_0
PA6.Signal=GPIO_Output
PA7.GPIO_Label=OUTPUT_1
PA7.Signal=GPIO_Output
PA8.GPIO_Label=RC_OUTPUT_3
PA8.Signal=S_TIM1_CH1
PA9.GPIO_Label=RC_OUTPUT_2
PA9.Signal=S_TIM1_CH2
PB0.GPIO_Label=OUTPUT_2
PB0.Signal=GPIO_Output
PB1.GPIO_Label=OUTPUT_3
PB1.Signal=GPIO_Output
PB11.GPIO_Label=SPEED_SENSOR
PB11.Signal=S_TIM2_CH4
PB2.GPIO_Label=RPI_POWER_OFF_OK
PB2.Signal=GPIO_Input
PB3.GPIO_Label=UART_TX
PB3.Signal=USART2_TX
PB4.GPIO_Label=UART_RX
PB4.Signal=USART2_RX
PB7.Signal=I2C1_SDA
PB8-BOOT0.Signal=I2C1_SCL
PB9.GPIO_Label=REG_5V_EN
PB9.Signal=GPIO_Output
PC13.GPIO_Label=POWER_SWITCH
PC13.Signal=GPIO_Input

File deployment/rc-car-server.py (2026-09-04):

#!/usr/bin/env python3
"""WebSocket-to-STM32 UART bridge for the RC car on Raspberry Pi.

Protokoll (matchar webbappens useCarSocket):
  in : {"ping": <ms-timestamp>}            -> ut: {"pong": <samma>}
  in : {"action": "estop"|"resume"|"photo", "value": ...}
  in : {"rc": [..4 values -1000..1000], "digital": 0..15, "buzzer": 0..65535}
  in : {"action": "oled", "value": {"base64"|"hex"|"framebuffer": <512 bytes>}}
  ut : {"speed":..,"rssi":..,"temperature":..,"heading":..,
        "recording":..,"estop":..,"armed":..,"stm32": {...}}

Kör:  python3 rc-car-server.py
"""

from __future__ import annotations

import asyncio
import json
import logging
import re
import base64
import hmac
import os
import shlex
import signal
import socket
import subprocess
import sys
import threading
import time
import urllib.request
from urllib.parse import parse_qs, urlparse

import config

logging.basicConfig(
    level=logging.INFO,
    format="%(asctime)s %(levelname)-7s %(name)s: %(message)s",
)
log = logging.getLogger("rc-car")

try:
    import websockets
    from websockets.server import serve
    from websockets.exceptions import ConnectionClosed
except ImportError:  # pragma: no cover
    log.error("websockets saknas. Installera: sudo apt-get install -y python3-websockets")
    sys.exit(1)

try:
    import serial  # type: ignore
except ImportError:  # pragma: no cover
    serial = None  # type: ignore[assignment]


MSG_CONTROL = 0x01
MSG_RPI_SHUTDOWN = 0x02
MSG_DISPLAY_DATA = 0x03
MSG_DISPLAY_UPDATE = 0x04
MSG_RPI_INFO = 0x05
MSG_STATUS = 0x80

MAX_PAYLOAD_SIZE = 64
CONTROL_PAYLOAD_SIZE = 11
STATUS_PAYLOAD_SIZE = 56
DISPLAY_FRAMEBUFFER_SIZE = 512
DISPLAY_CHUNK_DATA_SIZE = 63
DISPLAY_CHUNK_COUNT = 9
MAX_ENCODED_FRAME_SIZE = MAX_PAYLOAD_SIZE + 6


def clamp(value: float, low: float, high: float) -> float:
    return max(low, min(high, value))


def crc16_ccitt(data: bytes) -> int:
    crc = 0xFFFF
    for byte in data:
        crc ^= byte << 8
        for _ in range(8):
            if crc & 0x8000:
                crc = ((crc << 1) ^ 0x1021) & 0xFFFF
            else:
                crc = (crc << 1) & 0xFFFF
    return crc


def cobs_encode(data: bytes) -> bytes:
    encoded = bytearray([0])
    code_index = 0
    code = 1

    for byte in data:
        if byte == 0:
            encoded[code_index] = code
            code_index = len(encoded)
            encoded.append(0)
            code = 1
        else:
            encoded.append(byte)
            code += 1
            if code == 0xFF:
                encoded[code_index] = code
                code_index = len(encoded)
                encoded.append(0)
                code = 1

    encoded[code_index] = code
    return bytes(encoded)


def cobs_decode(data: bytes) -> bytes:
    decoded = bytearray()
    index = 0

    while index < len(data):
        code = data[index]
        index += 1
        if code == 0:
            raise ValueError("zero byte inside COBS frame")

        end = index + code - 1
        if end > len(data):
            raise ValueError("COBS code byte overruns frame")

        decoded.extend(data[index:end])
        index = end
        if code != 0xFF and index < len(data):
            decoded.append(0)

    return bytes(decoded)


def encode_packet(msg_type: int, payload: bytes = b"") -> bytes:
    if len(payload) > MAX_PAYLOAD_SIZE:
        raise ValueError(f"payload too large: {len(payload)} > {MAX_PAYLOAD_SIZE}")

    packet = bytes([msg_type, len(payload)]) + payload
    packet += crc16_ccitt(packet).to_bytes(2, "little")
    return cobs_encode(packet) + b"\x00"


def decode_packet(frame: bytes) -> tuple[int, bytes]:
    decoded = cobs_decode(frame)
    if len(decoded) < 4:
        raise ValueError("decoded packet too short")

    msg_type = decoded[0]
    payload_length = decoded[1]
    if payload_length > MAX_PAYLOAD_SIZE or len(decoded) != payload_length + 4:
        raise ValueError("invalid decoded packet length")

    received_crc = int.from_bytes(decoded[-2:], "little")
    calculated_crc = crc16_ccitt(decoded[:-2])
    if received_crc != calculated_crc:
        raise ValueError(f"CRC mismatch rx=0x{received_crc:04x} calc=0x{calculated_crc:04x}")

    return msg_type, decoded[2:-2]


def parse_status_payload(payload: bytes) -> dict:
    if len(payload) != STATUS_PAYLOAD_SIZE:
        raise ValueError(f"wrong STATUS length: {len(payload)}")

    speed_hz_x100 = int.from_bytes(payload[47:51], "little")
    bus_mv = int.from_bytes(payload[51:53], "little")
    current_ma = int.from_bytes(payload[53:55], "little", signed=True)
    return {
        "stm32": {
            "uptimeMs": int.from_bytes(payload[0:4], "little"),
            "rc": [
                int.from_bytes(payload[4:6], "little", signed=True),
                int.from_bytes(payload[6:8], "little", signed=True),
                int.from_bytes(payload[8:10], "little", signed=True),
                int.from_bytes(payload[10:12], "little", signed=True),
            ],
            "digitalMask": payload[12],
            "buzzerHz": int.from_bytes(payload[14:16], "little"),
            "uartRxFrames": int.from_bytes(payload[16:20], "little"),
            "uartCrcErrors": int.from_bytes(payload[20:24], "little"),
            "failsafeCount": int.from_bytes(payload[24:28], "little"),
            "rpiConnected": bool(int.from_bytes(payload[28:30], "little")),
            "rpiPowerEnabled": bool(payload[30]),
            "rpiPoweroffOk": bool(payload[31]),
            "rpiShutdownRequested": bool(payload[32]),
            "rpiStatus": payload[33],
            "analogRaw": [
                int.from_bytes(payload[34:36], "little"),
                int.from_bytes(payload[36:38], "little"),
                int.from_bytes(payload[38:40], "little"),
                int.from_bytes(payload[40:42], "little"),
            ],
            "ntcRaw": int.from_bytes(payload[42:44], "little"),
            "tmp75C": int.from_bytes(payload[44:46], "little", signed=True) / 100.0,
            "tmp75Valid": bool(payload[46]),
            "speedHz": speed_hz_x100 / 100.0,
            "ina226VoltageV": bus_mv / 1000.0,
            "ina226CurrentA": current_ma / 1000.0,
            "ina226Valid": bool(payload[55]),
        },
        "battery": bus_mv / 1000.0 if bus_mv else None,
        "speed": speed_hz_x100 / 100.0,
        "temperature": int.from_bytes(payload[44:46], "little", signed=True) / 100.0,
        "failsafe": bool(payload[13]),
    }


def _int_auto(value, default: int = 0) -> int:
    try:
        if isinstance(value, str):
            return int(value, 0)
        return int(value)
    except (TypeError, ValueError):
        return default
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

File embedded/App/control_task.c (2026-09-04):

#include "control_task.h"

#include "app_config.h"
#include "buzzer.h"
#include "main.h"

#define CONTROL_FAILSAFE_TIMEOUT_MS 1000u
#define RC_COMMAND_MIN (-1000)
#define RC_COMMAND_MAX 1000
#define RC_PULSE_MIN_US 1000u
#define RC_PULSE_NEUTRAL_US 1500u
#define RC_PULSE_MAX_US 2000u
#define RC_OUTPUT_COUNT 4u
#define DIGITAL_OUTPUT_MASK_ALL 0x0fu

static TIM_HandleTypeDef *control_rc_output_timer;
static rover_state_t *control_state;
static rover_diag_t *control_diag;
static uint32_t last_control_message_ms;
static bool previous_failsafe_active = true;
static bool forced_failsafe_active = true;

static const uint32_t rc_output_channels[RC_OUTPUT_COUNT] =
{
  TIM_CHANNEL_4, /* RC output 0, PA11 */
  TIM_CHANNEL_3, /* RC output 1, PA10 */
  TIM_CHANNEL_2, /* RC output 2, PA9 */
  TIM_CHANNEL_1  /* RC output 3, PA8 */
};

static int16_t clamp_command(int16_t value)
{
  if (value < RC_COMMAND_MIN)
  {
    return RC_COMMAND_MIN;
  }
  if (value > RC_COMMAND_MAX)
  {
    return RC_COMMAND_MAX;
  }
  return value;
}

static uint32_t command_to_pulse_us(int16_t value)
{
  int32_t clamped = clamp_command(value);
  int32_t span = (int32_t)(RC_PULSE_MAX_US - RC_PULSE_MIN_US);
  return (uint32_t)((int32_t)RC_PULSE_NEUTRAL_US + ((clamped * span) / (2 * RC_COMMAND_MAX)));
}

static void set_rc_compare(uint32_t channel, uint32_t pulse_us)
{
  if (control_rc_output_timer != 0)
  {
    __HAL_TIM_SET_COMPARE(control_rc_output_timer, channel, pulse_us);
  }
}

void rc_output_set(uint8_t output, int16_t value)
{
  if (output < RC_OUTPUT_COUNT)
  {
    set_rc_compare(rc_output_channels[output], command_to_pulse_us(value));
  }
}

void digital_outputs_set(uint8_t output_mask)
{
  uint8_t masked_outputs = (uint8_t)(output_mask & DIGITAL_OUTPUT_MASK_ALL);

  HAL_GPIO_WritePin(OUTPUT_0_GPIO_Port, OUTPUT_0_Pin, ((masked_outputs & 0x01u) != 0u) ? GPIO_PIN_SET : GPIO_PIN_RESET);
  HAL_GPIO_WritePin(OUTPUT_1_GPIO_Port, OUTPUT_1_Pin, ((masked_outputs & 0x02u) != 0u) ? GPIO_PIN_SET : GPIO_PIN_RESET);
  HAL_GPIO_WritePin(OUTPUT_2_GPIO_Port, OUTPUT_2_Pin, ((masked_outputs & 0x04u) != 0u) ? GPIO_PIN_SET : GPIO_PIN_RESET);
  HAL_GPIO_WritePin(OUTPUT_3_GPIO_Port, OUTPUT_3_Pin, ((masked_outputs & 0x08u) != 0u) ? GPIO_PIN_SET : GPIO_PIN_RESET);
}

static void apply_safe_outputs(void)
{
  for (uint8_t output = 0u; output < RC_OUTPUT_COUNT; output++)
  {
    rc_output_set(output, 0);
  }
  digital_outputs_set(0u);
  buzzer_stop();
}

static void store_safe_state(void)
{
  if (control_state == 0)
  {
    return;
  }

  for (uint8_t output = 0u; output < RC_OUTPUT_COUNT; output++)
  {
    control_state->rc_command[output] = 0;
  }
  control_state->digital_output_mask = 0u;
  control_state->buzzer_frequency_hz = 0u;
}

static void apply_state_outputs(void)
{
  if (control_state == 0)
  {
    return;
  }

  for (uint8_t output = 0u; output < RC_OUTPUT_COUNT; output++)
  {
    rc_output_set(output, control_state->rc_command[output]);
  }
  digital_outputs_set(control_state->digital_output_mask);
  if (control_state->buzzer_frequency_hz == 0u)
  {
    buzzer_stop();
  }
  else
  {
    buzzer_start(control_state->buzzer_frequency_hz);
  }
}

void control_task_init(TIM_HandleTypeDef *rc_output_timer, rover_state_t *state, rover_diag_t *diag)
{
  control_rc_output_timer = rc_output_timer;
  control_state = state;
  control_diag = diag;
  last_control_message_ms = HAL_GetTick();

  apply_safe_outputs();
  store_safe_state();

  if (control_rc_output_timer != 0)
  {
    (void)HAL_TIM_PWM_Start(control_rc_output_timer, TIM_CHANNEL_1);
    (void)HAL_TIM_PWM_Start(control_rc_output_timer, TIM_CHANNEL_2);
    (void)HAL_TIM_PWM_Start(control_rc_output_timer, TIM_CHANNEL_3);
    (void)HAL_TIM_PWM_Start(control_rc_output_timer, TIM_CHANNEL_4);
  }
}

void control_task_apply_command(const int16_t rc_command[4], uint8_t digital_output_mask, uint16_t buzzer_frequency_hz, uint32_t now_ms)
{
  uint8_t masked_outputs = (uint8_t)(digital_output_mask & DIGITAL_OUTPUT_MASK_ALL);

  if (rc_command == 0)
  {
    return;
  }

  last_control_message_ms = now_ms;

  if (control_state != 0)
  {
    for (uint8_t output = 0u; output < RC_OUTPUT_COUNT; output++)
    {
      control_state->rc_command[output] = clamp_command(rc_command[output]);
    }
    control_state->digital_output_mask = masked_outputs;
    control_state->buzzer_frequency_hz = buzzer_frequency_hz;
  }

#if APP_CONTROL_FAILSAFE_ENABLED
  if (forced_failsafe_active)
  {
    apply_safe_outputs();
    return;
  }
#else
  (void)forced_failsafe_active;
#endif

  apply_state_outputs();
}

void control_task_set_forced_failsafe(bool enabled)
{
#if APP_CONTROL_FAILSAFE_ENABLED
  bool was_forced_failsafe_active = forced_failsafe_active;
  forced_failsafe_active = enabled;
  if (enabled)
  {
    store_safe_state();
    apply_safe_outputs();
  }
  else if (was_forced_failsafe_active &&
           ((uint32_t)(HAL_GetTick() - last_control_message_ms) < CONTROL_FAILSAFE_TIMEOUT_MS))
  {
    apply_state_outputs();
  }
#else
  (void)enabled;
  forced_failsafe_active = false;
  previous_failsafe_active = false;
  if (control_state != 0)
  {
    control_state->failsafe_active = false;
  }
#endif
}

void control_task(void)
{
#if APP_CONTROL_FAILSAFE_ENABLED
  uint32_t now_ms = HAL_GetTick();
  bool communication_timeout = (uint32_t)(now_ms - last_control_message_ms) >= CONTROL_FAILSAFE_TIMEOUT_MS;
  bool failsafe_active = forced_failsafe_active || communication_timeout;

  if (control_state != 0)
  {
    control_state->failsafe_active = failsafe_active;

    if (failsafe_active)
    {
      store_safe_state();
      apply_safe_outputs();
    }
  }

  if ((control_diag != 0) && failsafe_active && !previous_failsafe_active)
  {
    control_diag->failsafe_count++;
  }
  previous_failsafe_active = failsafe_active;
#else
  forced_failsafe_active = false;
  previous_failsafe_active = false;
  if (control_state != 0)
  {
    control_state->failsafe_active = false;
  }
#endif
}

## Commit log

2026-08-19 Inital electronics and schematics
2026-08-19 3D models of board and accessories
    [RASPBERRY PI 3 + Female Header.SLDASM, RASPBERRY PI 3 + Female Header.STEP, mainboard.SLDASM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]
2026-08-19 STM32CubeMX first version
2026-08-19 Fixed correct channels för ADC1 plus some better gitignore file
    [embedded.ioc, main.c]
2026-08-22 Added a ADC counter for trouble shooting
2026-08-30 Updated protocol and included new documentation
    [bom.csv]
2026-09-02 UART test tool
2026-09-02 fixed circular dma error
    [embedded.ioc, uart_task.c]
2026-09-02 Create service WebSocket<->UART
2026-09-03 more robust against error in frames
    [rc-car-server.py]
2026-09-03 Added a heatbeat signal
2026-09-03 Improvements of UART handling
2026-09-03 Fix sudo for powering off
2026-09-03 Make usre it has access to poweroff
2026-09-04 Added a buzzer sound when turning on/off the rpi
    [app.c, buzzer.c, pi_status_task.c]

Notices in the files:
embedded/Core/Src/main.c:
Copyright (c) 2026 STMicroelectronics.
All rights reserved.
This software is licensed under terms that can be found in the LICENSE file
